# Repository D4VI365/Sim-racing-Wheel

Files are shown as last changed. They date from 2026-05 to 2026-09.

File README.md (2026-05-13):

# Sim racing Wheel
I'm building a custom direct drive force feedback wheel for simracing

The device is powered by a 24V Power supply. It is a direct drive force feedback sim racing wheels that can theoretically deliver up to 15Nm of torque. It uses a 6.5" hoverboard motor, an ODESK V4.2 and a 500Pr E6B2-CWZ6C encoder with a 3:1 ratio to have a better resolution. for the software I'm using the FFBeats software and a custom written program to control the buttons. They have a separate custom board to have a simpler and more manageable interface. All the pieces are assembled using M6 nuts and bolts except from the grips and the belt tensioner that use M3 screws and heat inserts.

Full assembly:
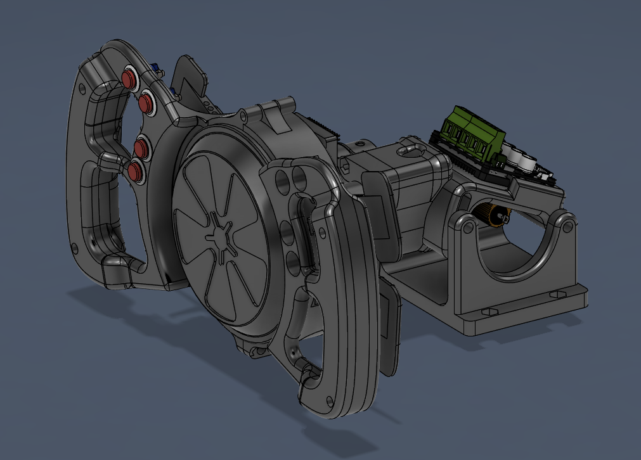
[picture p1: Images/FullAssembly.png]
FullAssembly


Wheel:
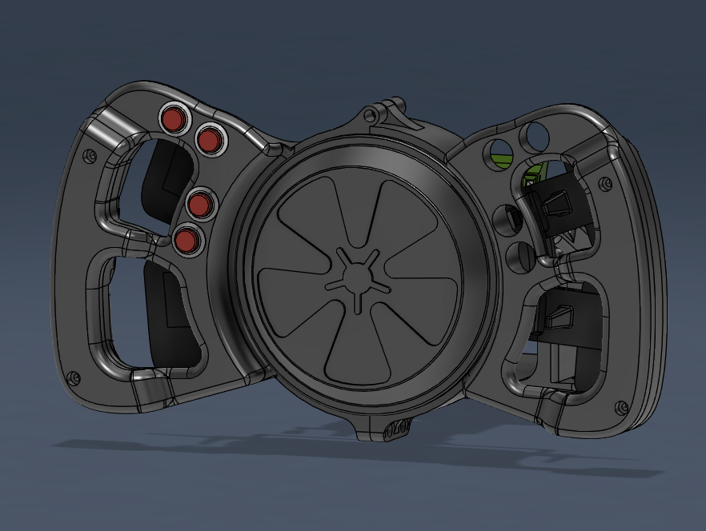
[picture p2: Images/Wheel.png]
Wheel


PCB layout:
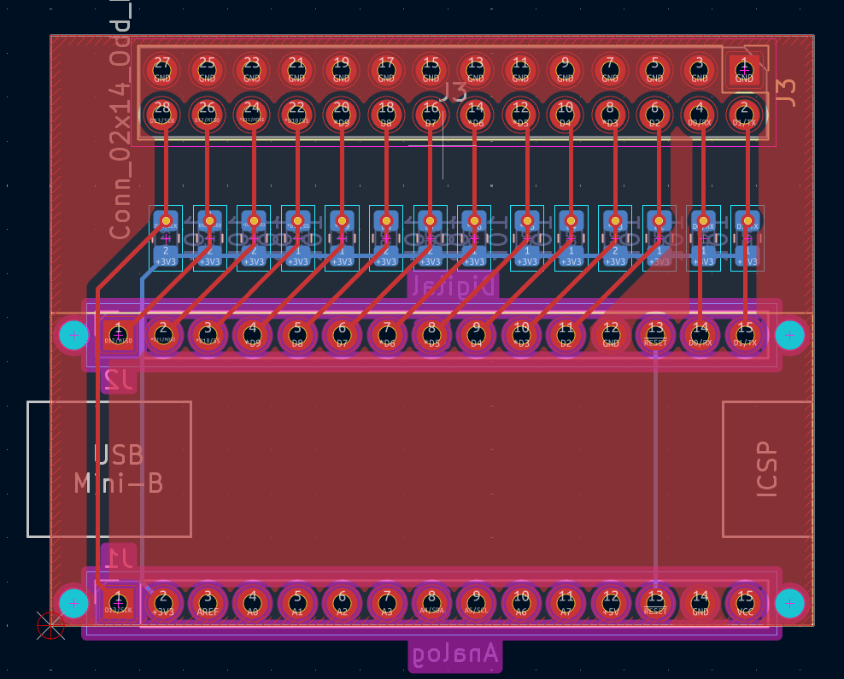
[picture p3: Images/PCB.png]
PCB


Electrical scheme:
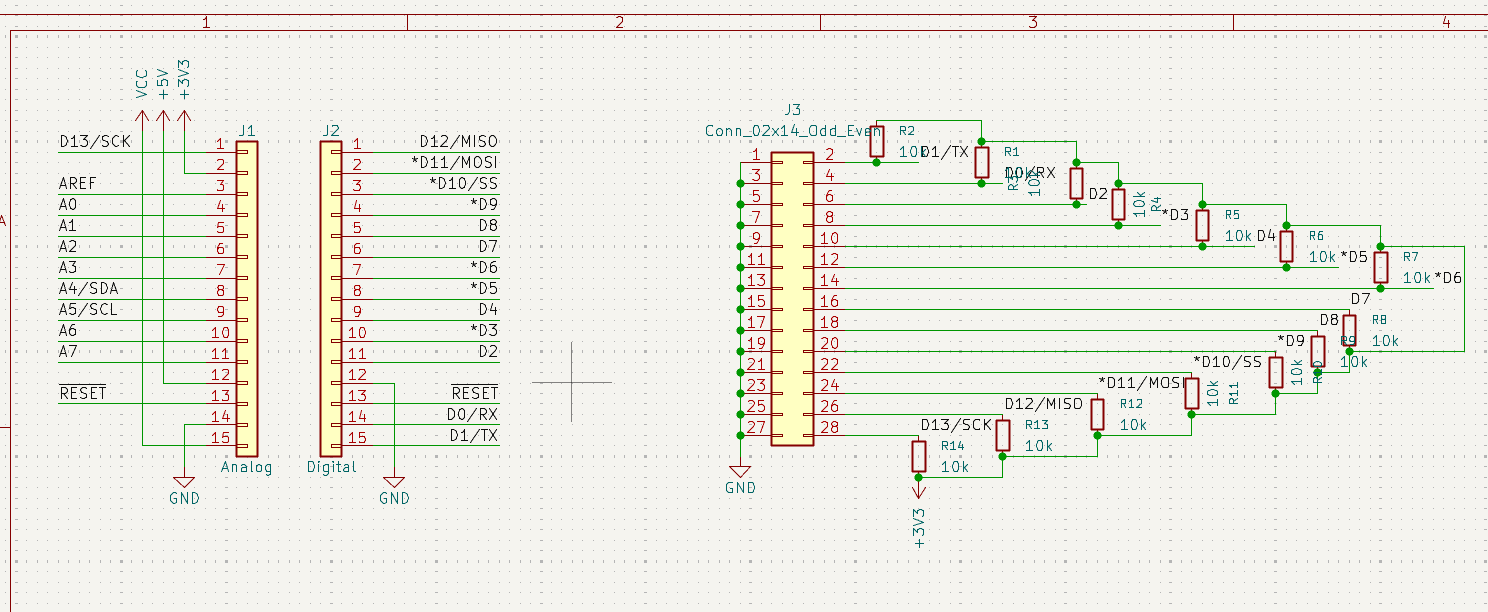
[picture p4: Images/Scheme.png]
Scheme


| Name | Purpose | Quantity | Total Cost (USD) | Link | Distributor |
|---|---|---|---|---|---|
| M6 threaded rod | making the inclination adjustable | 1 | 4.60 | https://it.aliexpress.com/item/1005008168724880.html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 | Aliexpress  |
| M6 nuts and bolts | holding the pieces together | 1 | 8.19 | https://it.aliexpress.com/item/1005011593584495.html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 | Aliexpress  |
| PCB | Connecting and controlling all the buttons | 1 | 2.00 | https://jlcpcb.com | JLCPCB |
| 6.5"" 350W brushless motor | Force feedback motor | 1 | 45.00 | https://www.aliexpress.com/item/1005010742922270.html?spm=a2g0o.cart.0.0.252f18fc3qqzs7&mp=1 | Vinted |
| 500PR E6B2-CWZ6C | obtaining the wheel position | 1 | 25.20 | https://www.aliexpress.com/item/1005009080411213.html?spm=a2g0o.cart.0.0.252f18fc3qqzs7&mp=1 | Aliexpress  |
| Odesk v4.2 | Motor driver | 1 | 46.65 | https://www.aliexpress.com/item/1005005725467528.html?spm=a2g0o.cart.0.0.252f18fc3qqzs7&mp=1 | Aliexpress  |
| 16mm Button | Utility buttons | 8 | 4.86 | https://www.aliexpress.com/item/1005008839427718.html?spm=a2g0o.cart.0.0.252f18fc3qqzs7&mp=1 | Aliexpress  |
| 2GT 20T pulley | transmitting power to the encoder | 1 | 3.25 | https://www.aliexpress.com/item/1005006217674592.html?spm=a2g0o.cart.0.0.252f18fc3qqzs7&mp=1 | Aliexpress  |
| Teethless 2GT 20T pulley | tensioning the belt | 1 | 2.67 | https://www.aliexpress.com/item/1005006739452921.html?spm=a2g0o.cart.0.0.252f18fc3qqzs7&mp=1 | Aliexpress  |
| limit switch | paddles buttons | 4 | 4.51 | https://www.aliexpress.com/item/32273125391.html?spm=a2g0o.cart.0.0.252f18fc3qqzs7&mp=1 | Aliexpress  |
| 10x10x2 magnets | magnetic paddles | 4 | 3.13 | https://www.aliexpress.com/item/1005010075198458.html?spm=a2g0o.cart.0.0.252f18fc3qqzs7&mp=1 | Aliexpress  |
| 10-280mm 2GT belt | transmitting power to the encoder | 1 | 1.86 | https://www.aliexpress.com/item/1005009550451001.html?spm=a2g0o.cart.0.0.252f18fc3qqzs7&mp=1 | Aliexpress  |
| 12V 400W PSU | Powering the wheel | 1 | 28.08 | https://www.aliexpress.com/item/1005008642209328.html?spm=a2g0o.cart.0.0.252f18fc3qqzs7&mp=1 | Aliexpress  |
| Arduino pro nano | Controlling the buttons interface board | 1 | 4.18 | https://www.aliexpress.com/item/1005006438510487.html?spm=a2g0o.cart.0.0.252f18fc3qqzs7&mp=1 | Aliexpress  |
| XT60 Connectors | Bringing power from the PSU | 1 | 1.58 | https://www.aliexpress.com/item/1005007356557188.html?spm=a2g0o.cart.0.0.252f18fc3qqzs7&mp=1 | Aliexpress  |

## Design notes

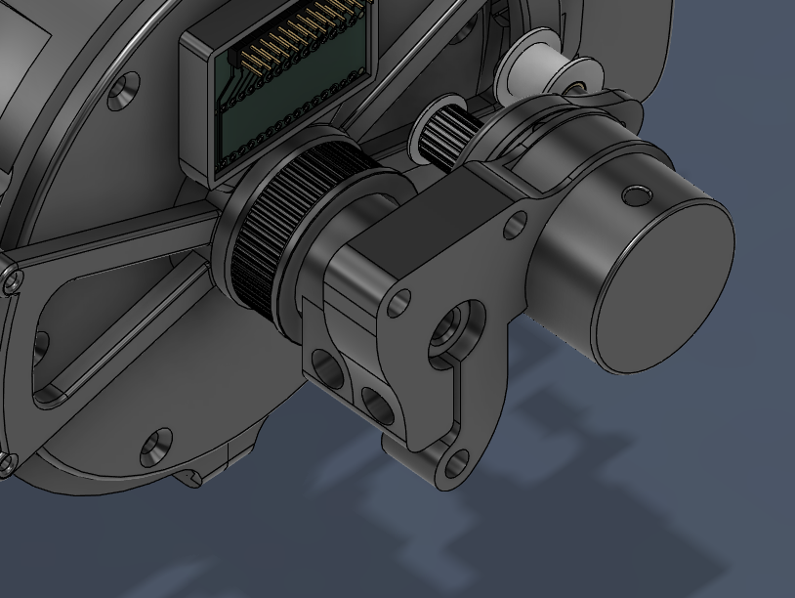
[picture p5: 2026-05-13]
Images/Screenshot 2026-05-06 211701.png

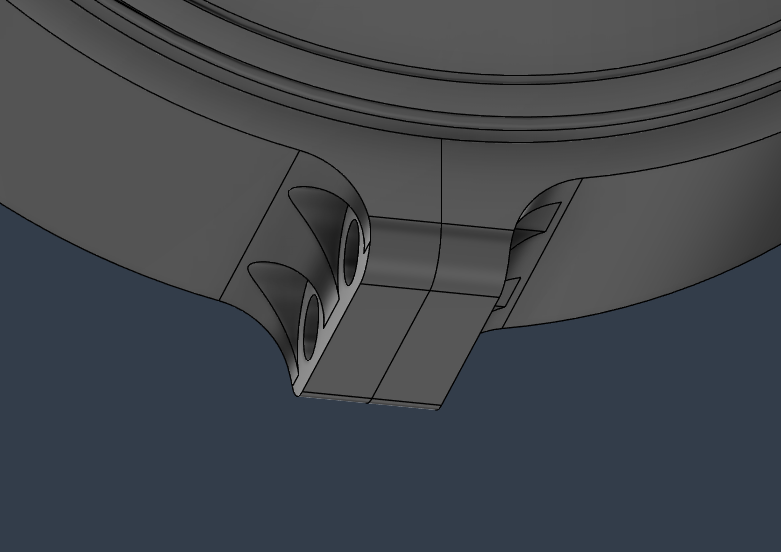
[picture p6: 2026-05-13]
Images/Screenshot 2026-05-04 213402.png

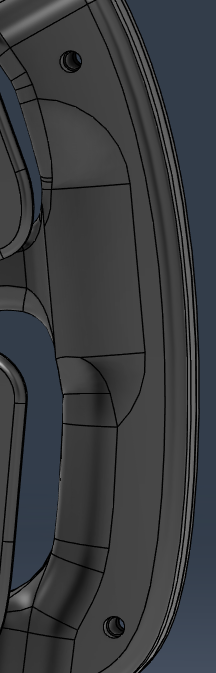
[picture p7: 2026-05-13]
Images/Screenshot 2026-05-06 211843.png

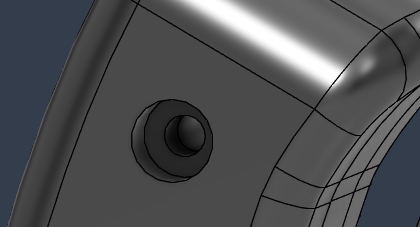
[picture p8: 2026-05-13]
Images/Screenshot 2026-05-06 211829.png

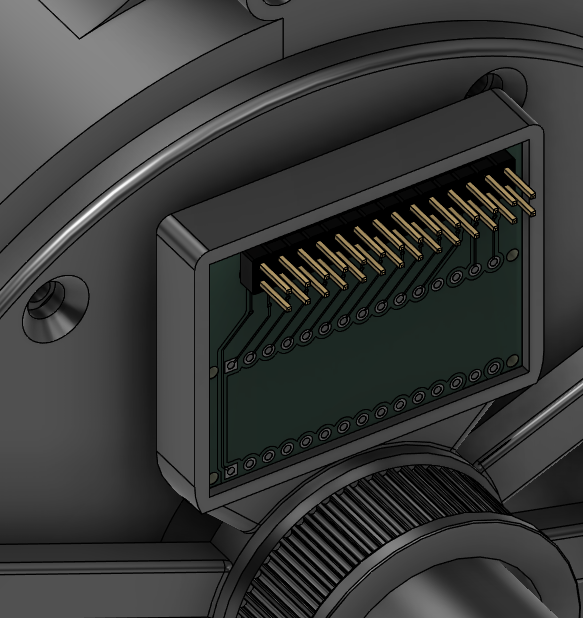
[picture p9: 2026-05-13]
Images/Screenshot 2026-05-05 222240.png

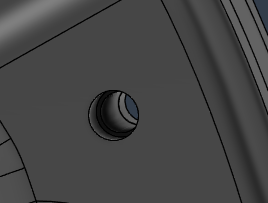
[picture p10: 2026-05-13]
Images/Screenshot 2026-05-06 211837.png

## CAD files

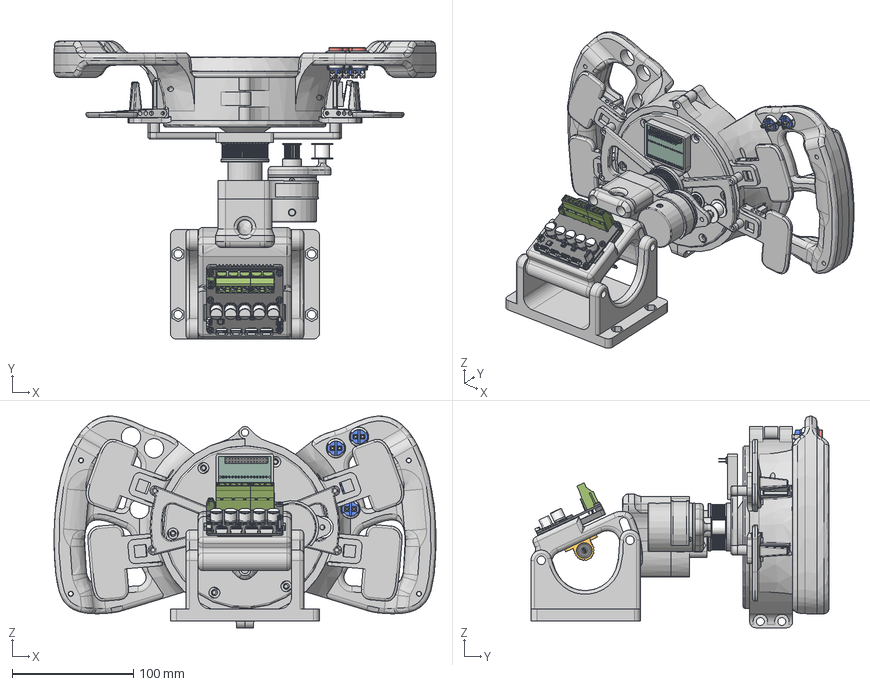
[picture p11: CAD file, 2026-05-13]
CAD/Assembly.step
314.7 x 245.6 x 174.3 mm
axle
cover_plate
motor_bell
6003-2RS
6202-2RS
button x 4
SWITCH_LIMITE
Componente2
PinHeader_2x14_P2.54mm_Vertical
R_0805_2012Metric x 14
SimWheelButtons_copper
SimWheelButtons_pad
SimWheelButtons_via
SimWheelButtons_soldermask
SimWheelButtons_soldermask_1
SimWheelButtons_PCB
countersunk flat head cross recess screw_iso_ISO 7046-1 - M2 x 3 - Z --- 3N x 3
E6B2-CWZ6C-1
instrument ball bearing_68_iso_ISO 1224 - 190615 - R,10,SI,NC,10_68
E6B2-CWZ6C-3
E6B2-CWZ6C-2
M4x0.7X5mm - flat-tip Set screw x 2
POWGE 2GT idler 20T B4

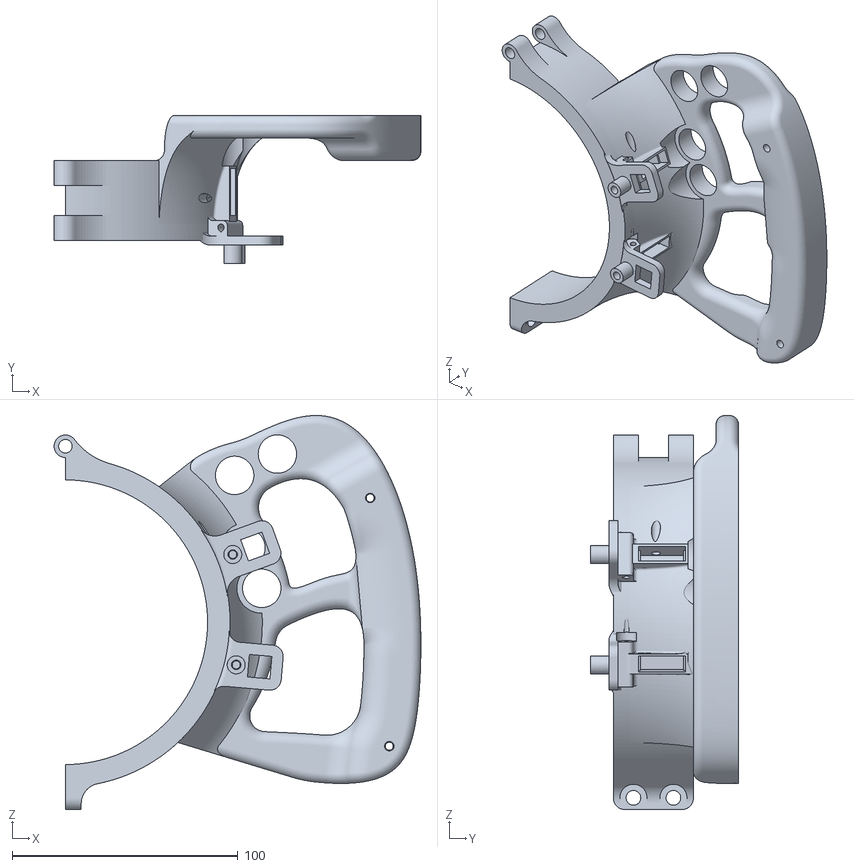
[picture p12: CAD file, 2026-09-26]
CAD/LBody.stl
162.4 x 65.6 x 174.4

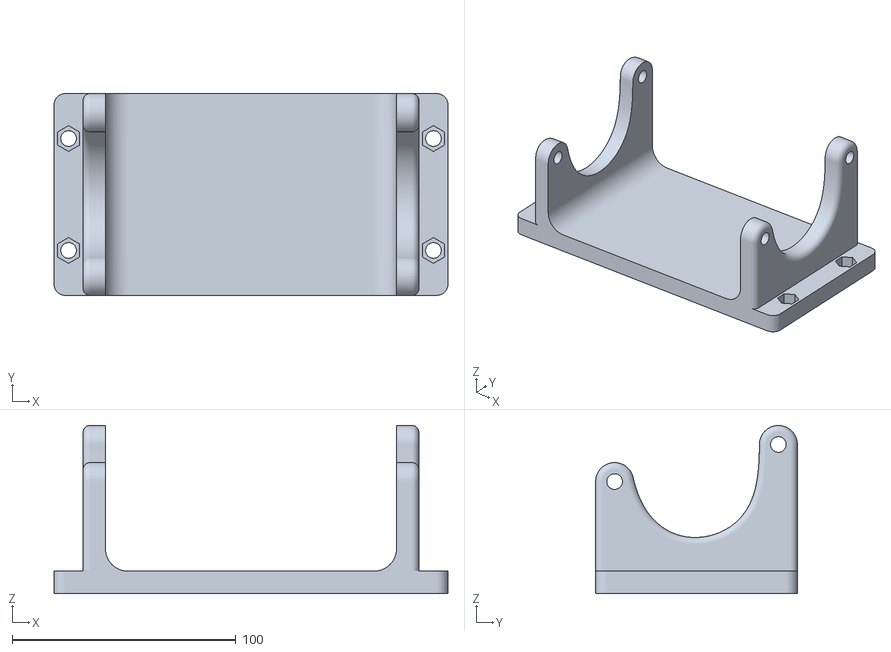
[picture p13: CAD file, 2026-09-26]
CAD/DeskMount.stl
176.0 x 90.1 x 75.1

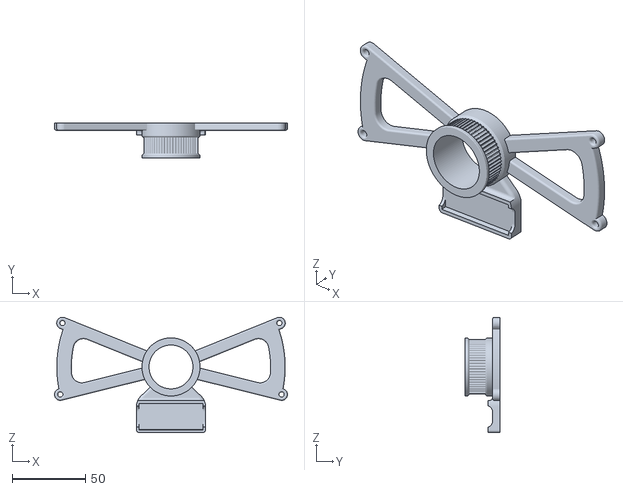
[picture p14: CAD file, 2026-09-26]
CAD/BackSupport.stl
159.4 x 24.0 x 79.0

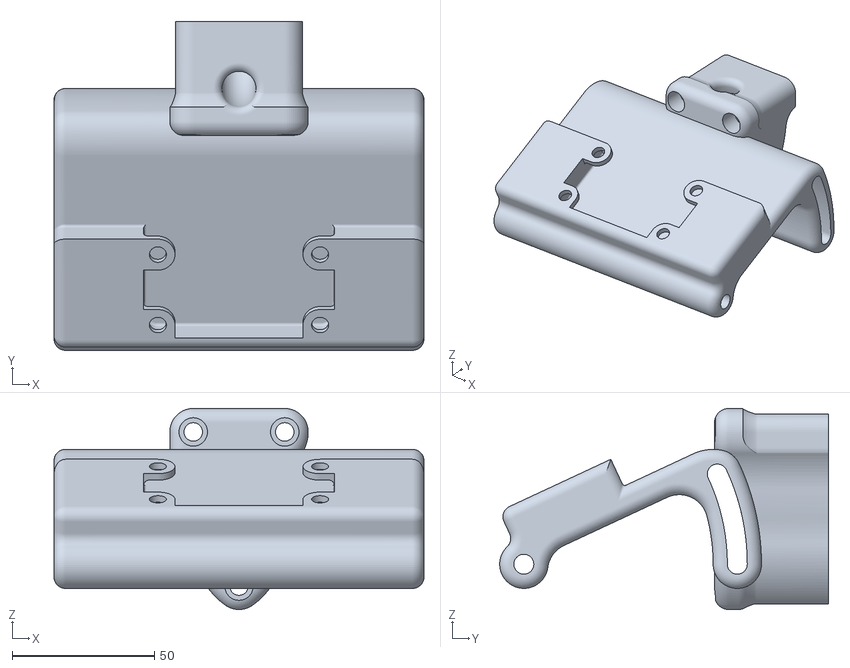
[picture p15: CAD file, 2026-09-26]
CAD/WheelMount.stl
130.0 x 115.5 x 70.7

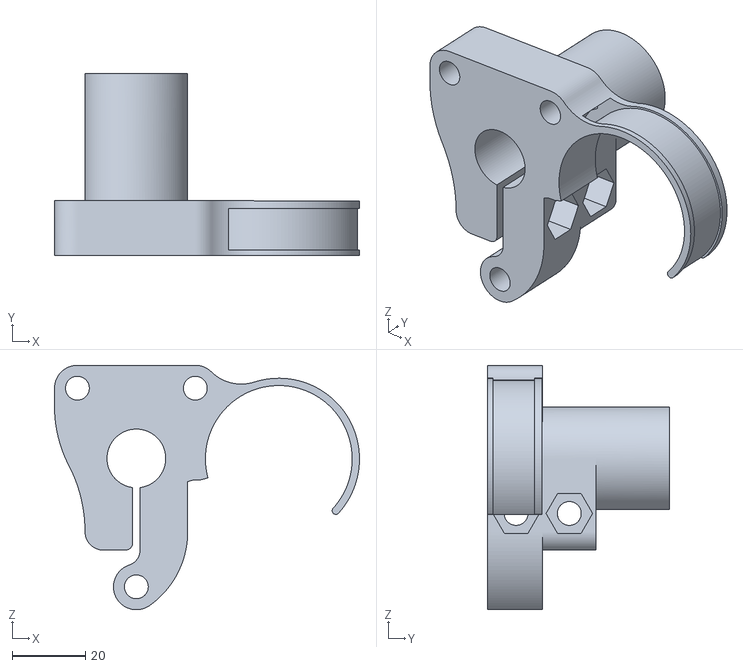
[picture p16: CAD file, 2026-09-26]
CAD/EncoderHolder.stl
83.1 x 49.5 x 66.7

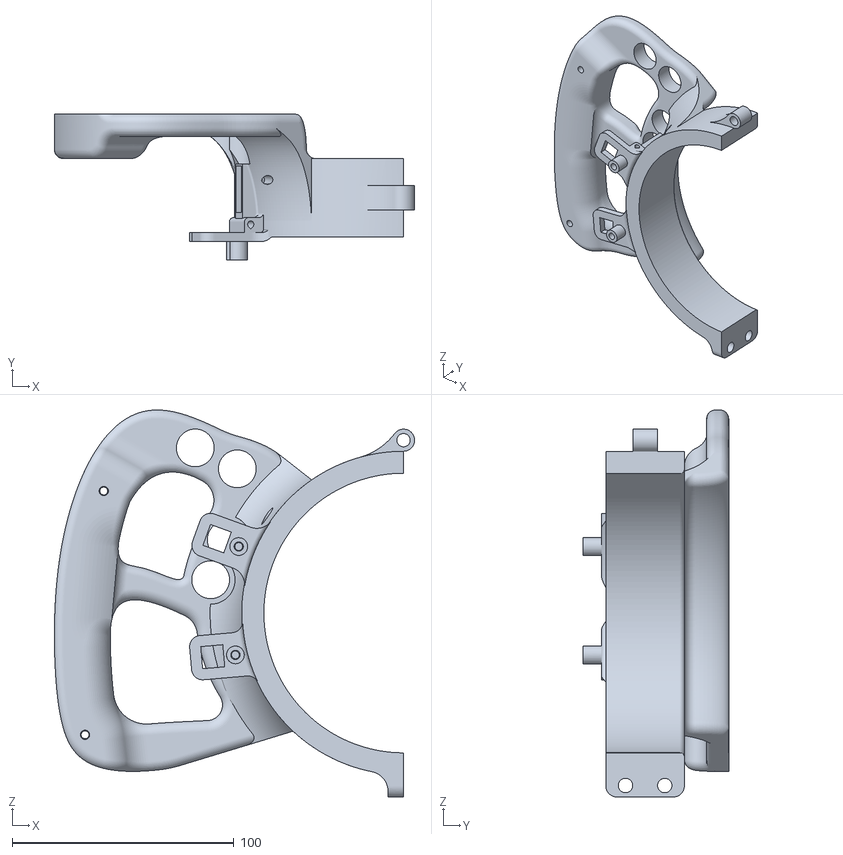
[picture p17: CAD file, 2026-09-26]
CAD/RBody.stl
162.4 x 65.6 x 174.4

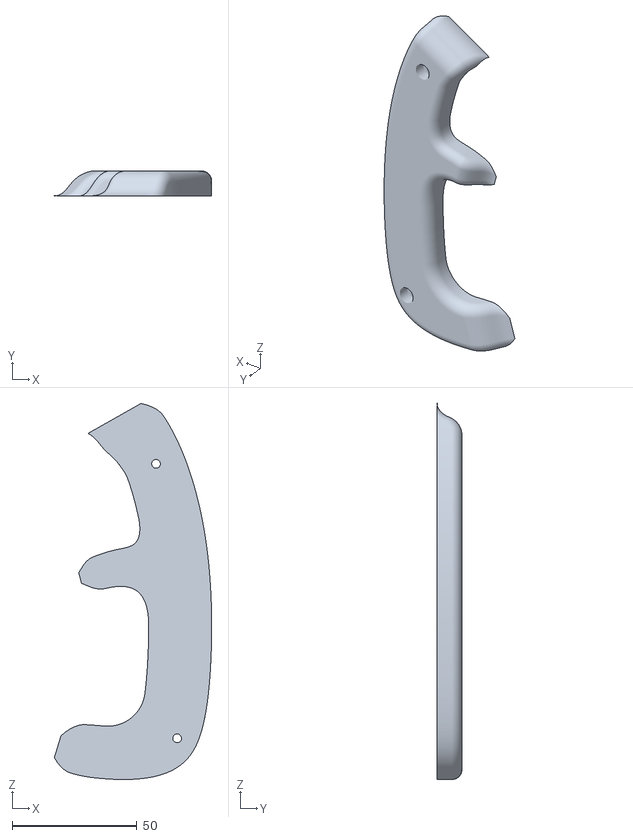
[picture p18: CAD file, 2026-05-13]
CAD/LGrip.stl
63.0 x 10.0 x 150.5

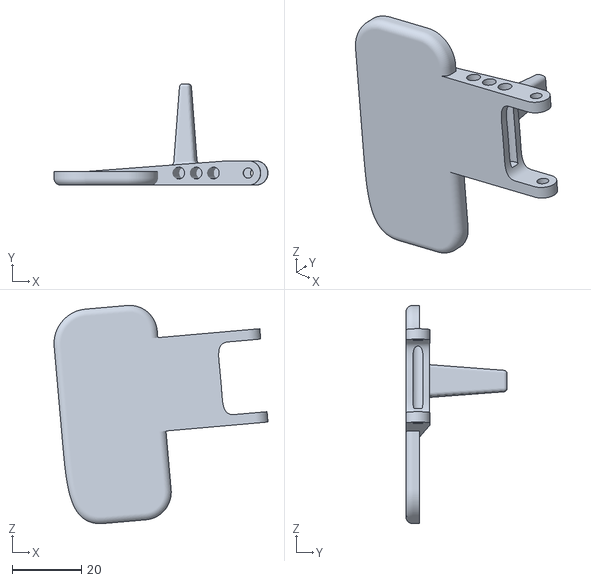
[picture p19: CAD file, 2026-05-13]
CAD/RLPaletta.stl
61.7 x 29.2 x 62.9

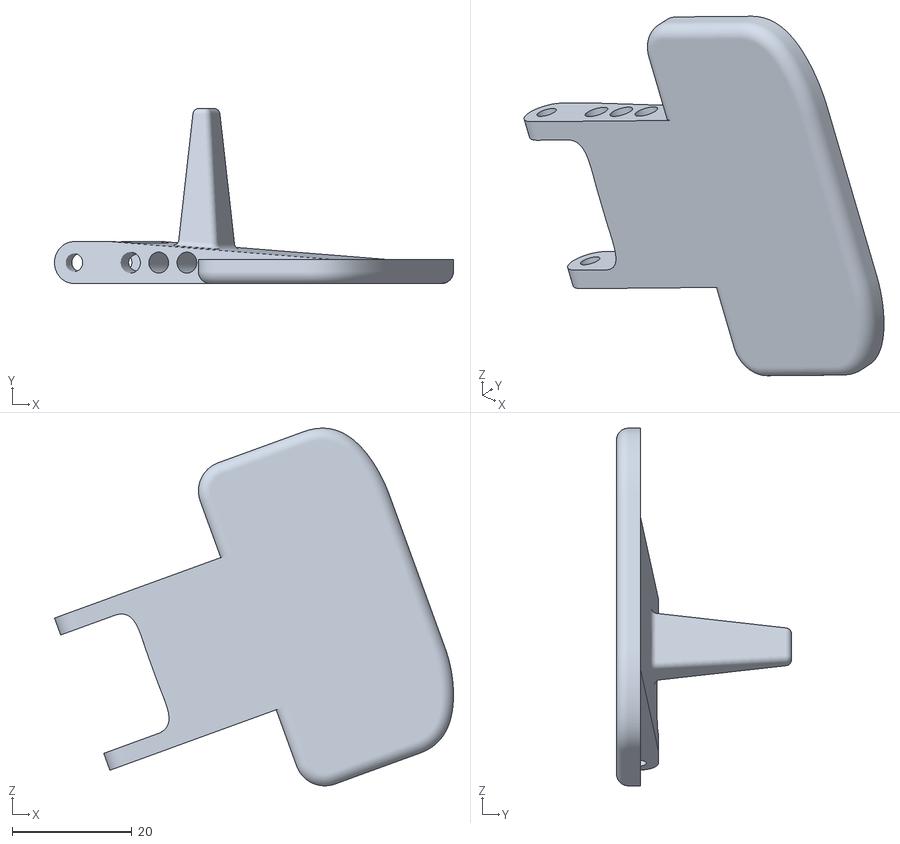
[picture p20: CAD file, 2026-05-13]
CAD/LUPaletta.stl
66.5 x 29.2 x 59.6

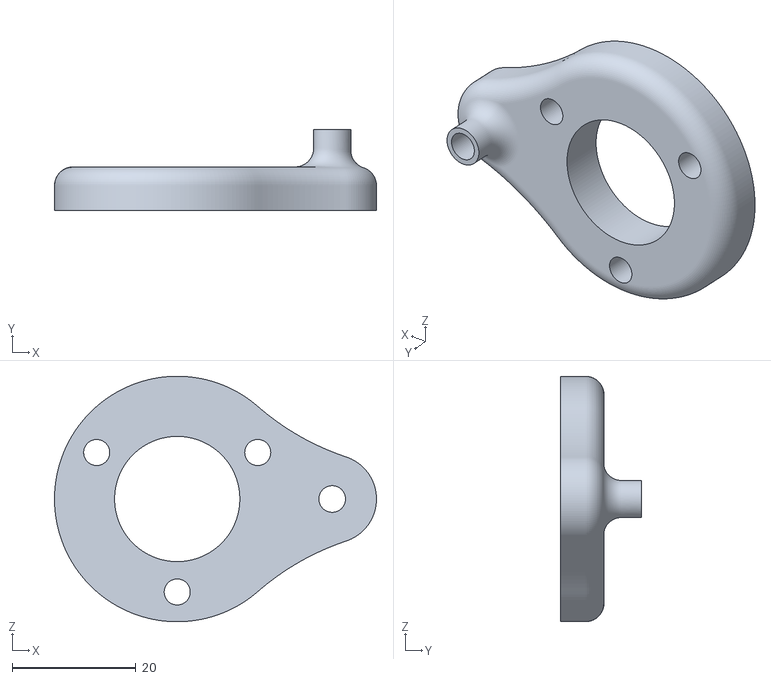
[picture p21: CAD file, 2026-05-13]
CAD/Tensioner.stl
51.9 x 13.0 x 39.6

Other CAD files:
CAD/RUPaletta.stl
CAD/RGrip.stl
CAD/LLPaletta.stl
CAD/Assembly.3mf

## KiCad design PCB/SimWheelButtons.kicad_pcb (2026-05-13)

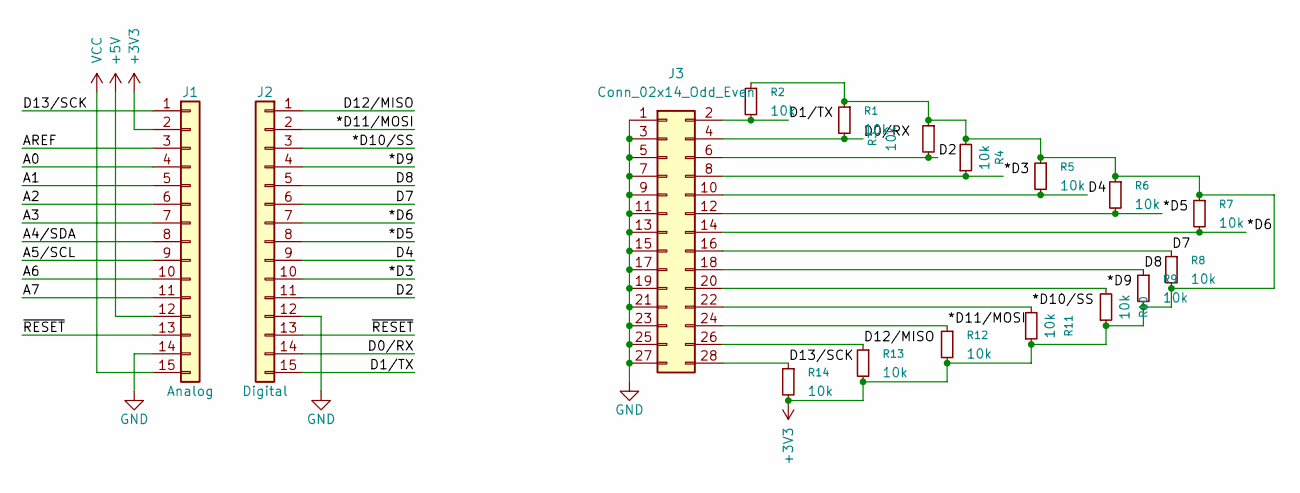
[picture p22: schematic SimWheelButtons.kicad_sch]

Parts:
J1: Analog; PinHeader_1x15_P2.54mm_Vertical
J2: Digital; PinHeader_1x15_P2.54mm_Vertical
J3: Conn_02x14_Odd_Even; PinHeader_2x14_P2.54mm_Vertical
R1, R2, R3, R4, R5, R6, R7, R8, R9, R10, R11, R12, R13, R14: 10k; R_0805_2012Metric_Pad1.20x1.40mm_HandSolder

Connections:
+3V3: J1.2, R1.1, R2.1, R3.1, R4.2, R5.1, R6.1, R7.1, R8.2, R9.2, R10.1, R11.1, R12.2, R13.2, R14.2
+5V: J1.12
/*D3: J2.10, J3.8, R4.1
/*D5: J2.8, J3.12, R6.2
/*D6: J2.7, J3.14, R7.2
/*D9: J2.4, J3.20, R10.2
/*D10/SS: J2.3, J3.22, R11.2
/*D11/MOSI: J2.2, J3.24, R12.1
/A0: J1.4
/A1: J1.5
/A2: J1.6
/A3: J1.7
/A4/SDA: J1.8
/A5/SCL: J1.9
/A6: J1.10
/A7: J1.11
/AREF: J1.3
/D0/RX: J2.14, J3.4, R1.2
/D1/TX: J2.15, J3.2, R2.2
/D2: J2.11, J3.6, R3.2
/D4: J2.9, J3.10, R5.2
/D7: J2.6, J3.16, R8.1
/D8: J2.5, J3.18, R9.1
/D12/MISO: J2.1, J3.26, R13.1
/D13/SCK: J1.1, J3.28, R14.1
/~RESET: J1.13, J2.13
GND: J1.14, J2.12, J3.1, J3.3, J3.5, J3.7, J3.9, J3.11, J3.13, J3.15, J3.17, J3.19, J3.21, J3.23, J3.25, J3.27
VCC: J1.15

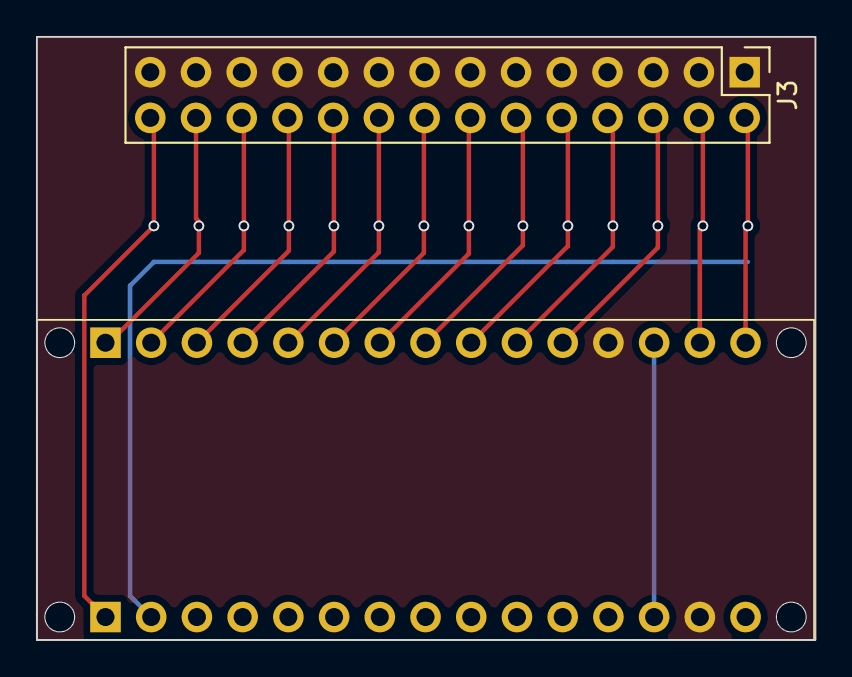
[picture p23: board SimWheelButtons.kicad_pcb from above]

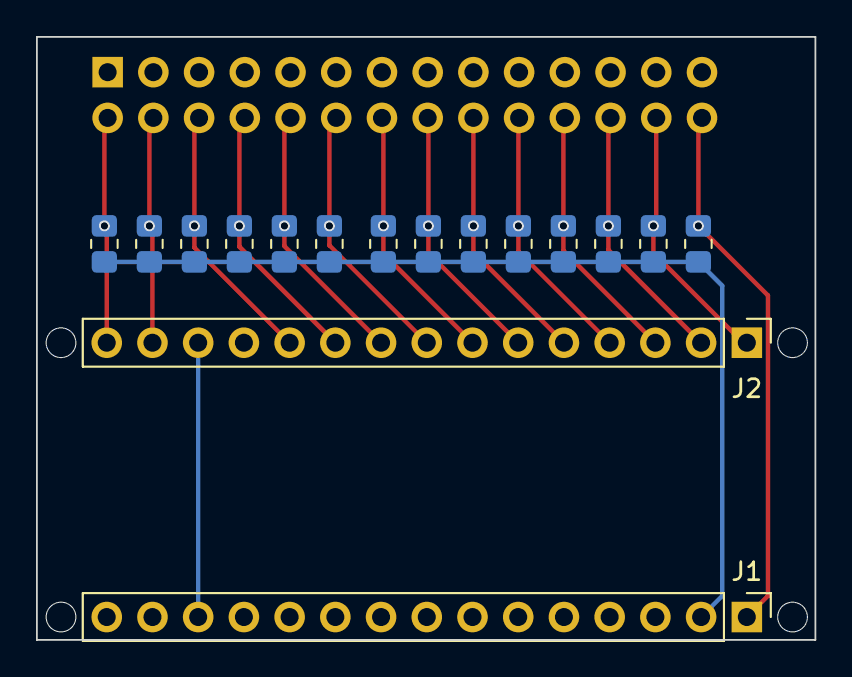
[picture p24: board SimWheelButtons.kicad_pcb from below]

Board: 2 copper layers, 43.2 x 33.5 mm, 21 parts (16 on the bottom side), 17 nets.

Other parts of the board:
MH1, MH2, MH3, MH4: MountingHole_65mil

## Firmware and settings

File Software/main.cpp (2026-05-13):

#include <Joystick.h>

// Definiamo i pin utilizzati come appaiono sul tuo schema J3
// I pin corrispondono ai nomi serigrafati sull'Arduino Pro Micro
const int buttonPins[] = {
  1,  // TX
  0,  // RX
  2,  // D2
  3,  // D3
  4,  // D4
  5,  // D5
  6,  // D6
  7,  // D7
  8,  // D8
  9,  // D9
  10, // D10
  16, // D11 (MOSI)
  14, // D12 (MISO)
  15  // D13 (SCK)
};

const int numButtons = 14;

// Inizializziamo il Joystick con 14 bottoni
// Tipo Joystick, numero bottoni, numero switch cappello, X, Y, Z, Rx, Ry, Rz, Rudder, Throttle, Accelerator, Brake, Steering
Joystick_ Joystick(0x03, JOYSTICK_TYPE_JOYSTICK, 
  numButtons, 0, // 14 bottoni, 0 hat switches
  false, false, false, // No assi X, Y, Z
  false, false, false, // No assi rotazione
  false, false,        // No rudder o throttle
  false, false, false  // No acceleratore, freno o sterzo
);

void setup() {
  // Configurazione dei pin come INPUT
  // Avendo le resistenze di pull-up da 10k esterne (R1-R14 nello schema),
  // il segnale sarà HIGH a riposo e LOW quando premi il tasto.
  for (int i = 0; i < numButtons; i++) {
    pinMode(buttonPins[i], INPUT);
  }

  Joystick.begin();
}

void loop() {
  for (int i = 0; i < numButtons; i++) {
    // Leggiamo lo stato del pin
    int currentState = digitalRead(buttonPins[i]);
    
    // Poiché hai pull-up esterne: 
    // HIGH (1) = Tasto rilasciato
    // LOW (0) = Tasto premuto
    // setButton vuole 1 per premuto, quindi invertiamo con '!'
    Joystick.setButton(i, !currentState);
  }
  
  // Piccolo delay per stabilità e per evitare di saturare il buffer USB
  delay(10);
}

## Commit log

2026-06-04 Add Gerber production files for PCB
    Add complete Gerber output for the SimWheelButtons PCB to PCB/Production. Includes top/bottom copper, soldermask, paste, silkscreen, edge cuts, NPTH/PTH drill files, .gbrjob and a Gerber.zip archive.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
    [SimWheelButtons-B_Cu.gbr, SimWheelButtons-B_Mask.gbr, SimWheelButtons-B_Paste.gbr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]
2026-09-26 Update CAD STL models
    Replace updated STL files for CAD components: BackSupport.stl, DeskMount.stl, EncoderHolder.stl, LBody.stl, RBody.stl, and WheelMount.stl. These are refreshed/exported versions of the parts (binary STL updates).
    [BackSupport.stl, DeskMount.stl, EncoderHolder.stl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]
